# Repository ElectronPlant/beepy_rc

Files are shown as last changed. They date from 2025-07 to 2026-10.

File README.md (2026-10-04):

# BeepyRC
Hobby project to make a RC rover platform using spare RC parts. The goal of this project is to develop a complete platform to support long term RC assisted missions.

Content summary

    * The platform is built on a custom PCB based on a STM32F4 microcontroller.
    * The firmware is implemented using FreeRTOS for simple and reliable multitasking and real-time operation.
    * The enclosure is fully 3d printable.
    * Support for off-the-shelf RC components with SBUS, 5V VTX power output, 3x standard servo outputs.

## Release 1 - [PoC] Nerf Blaster FPV Rover
Minimal-feature rover to support a simple, yet fun mission: exploring the house and firing a Nerf blaster in FPV (First-Person View).

The rover enables you to explore the house remotely using the RC interface and the FPV live feed provided by the video transmitter (VTX). The Nerf blaster and the VTX are mounted on a servo-operated arm, which controls their yaw and pitch angles. The arm provides two extra degrees of freedom to easily explore the room and aim the blaster. Once the target has been acquired, take the shot remotely using the aux channels of the RC remote.

### Complete Rover

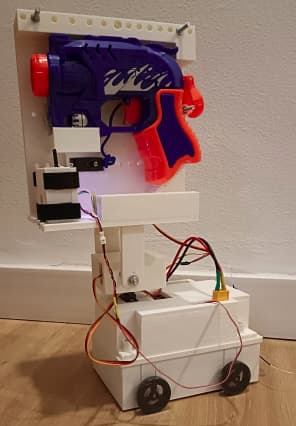
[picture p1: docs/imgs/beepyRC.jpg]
BeepyRc


### Custom PCB

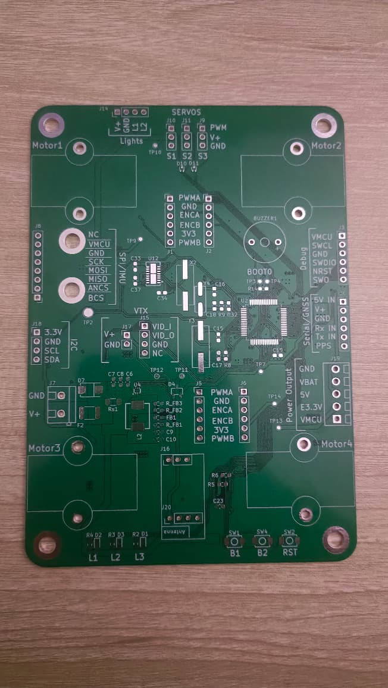
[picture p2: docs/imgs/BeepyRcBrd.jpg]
BeepyRcBrd


### Rover

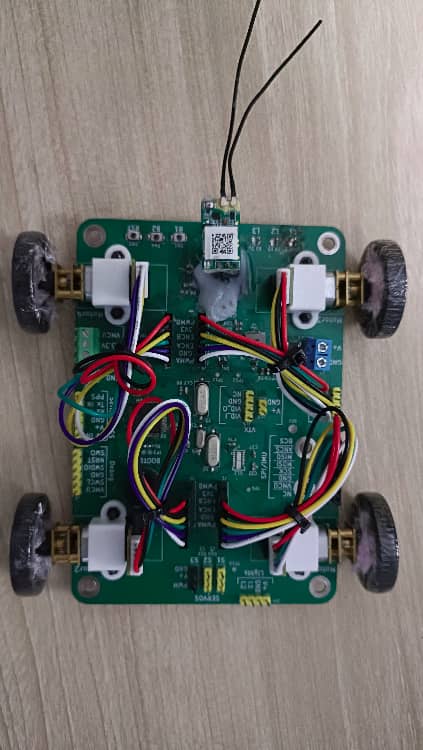
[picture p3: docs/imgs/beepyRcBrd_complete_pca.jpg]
PCA


---

# Documentation
For more information about the project check the documentation in ```docs/``` or deplay with [mkdocs](https://www.mkdocs.org/)

## Installing MKDOCS
run:
```
pip install mkdocs
```
or:
```
python -m pip install mkdocs
```

### Install the Material theme:
```
pip install mkdocs-material
```
or:
```
python -m pip install mkdocs-material
```

### Install mkdoxy
```
pip install mkdoxy
```
or
```
python -m pip install mkdoxy
```

### Install Doxygen
The installation procedure depends on the operating system, see: [Doxygen docs](https://www.doxygen.nl/manual/install.html)

For ubuntu:
```
sudo apt-get install doxygen
```

### Deploy docs
```
mkdocs serve
```

then the documentation will be served at:
```
http://127.0.0.1:8000/
```

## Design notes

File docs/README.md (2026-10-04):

# BeepyRC
Hobby project to make a RC rover platform using spare RC parts. The goal of this project is to develop a complete platform to support long term RC assisted missions.

## Project Roadmap
* [ ] __Release 1: PoC Nerf Blaster FPV Rover__
    * [x] Receive and parse the RC frames.
    * [x] Use RC inputs to control motors.
    * [x] Custom hardware for the RC rover.
    * [X] Control servos with aux channels (camera pan/tilt, fire nerf gun).
    * [X] 3D printed case.
* [ ] __Release 2: Sensor-Assisted Rover__
    * [ ] Motor encoders for precise individual motor adjustments.
    * [ ] Accelerometer, gyroscope and barometer integration speed and rotation RC setpoints.
* [ ] __Release 3: Waypoint Mission Rover__
    * [ ] Odometry + Kinematic movement estimation.
    * [ ] GPS integration for accurate rover position.
    * [ ] Support for autonomous waypoint missions.
* [ ] __Release 4: Autonomous Robotic Platform__

---

# Releases

Release table linking releases with the supported versions and tags.

| Release | FW Version | HW Version | Mech Version |
|---|---|---|---|
| __Rel. 1__  | FWv0.0 | beepyRcBrd_rev0.0 | TODO |

# Versions

Each component has its own versioning which are independent from the releases. This allows reusing a given version on multiple releases, or having multiple versions compatible between releases for patches and improvements.

## Firmware Versions

| Version | Tag | Description|
|---|---|---|
| __V 0.0__ | [FWv0.0](https://github.com/ElectronPlant/beepy_rc/releases/tag/FWv0.0) | Minimal features for Release 1 |

## Hardware

| Version | Tag | Schematics | Reworks | Fabrication Files| Description |
|---|---|---|---|---|---|
| __REV 0.0__ | [beepyRcBrd_rev0.0](https://github.com/ElectronPlant/beepy_rc/tree/beepyRcBrd_rev0.0)| [Schematics](beepyRcBrd/rev_0_0/beepyRcBrd_rev_0_0.pdf) | [Reworks](beepyRcBrd/rev_0_0/reworks.md) |[Fabrication Files](beepyRcBrd/rev_0_0/fabrication_files.zip)| Preliminary support for all planned features. Checkout the [design notes](beepyRcBrd/rev_0_0/design_notes.md). |

## Mechanical

| Version | Tag | STL Files| Description |
|---|---|---|---|
| __REV 0.0__ | [mech_rev0.0](https://github.com/ElectronPlant/beepy_rc/releases/tag/Mech_rev0.0)| [STL](mech/rev_0_0/BeepyRcMech_rev_0_0.zip) | See [Docs](mech/mech_docs.md) |

---

## Getting started

For information on how to get started with the template, refer to the:

* [Hardware](getting_started/hardware.md) page for information on how to setup the module and connect the LEDs used by the application.
* [Setup](getting_started/setup.md) page for a summarized description of how to get the STM32 development environment in a windows PC.

### Repository Organization

The documentation (as required by MkDocs) is placed in the ```docs\``` directory.

The application is implemented in the ```firmware/``` directory, see the [doxygen files output](template/files.md) for further information about the internal organization.

The design files for the custom PCB are located in the ```hardware/``` directory.

The 3D printed case is located in the ```mechanical/``` directory.

## Credits
This projects uses external libraries that are documented in the ```NOTICE.md``` file in the
project's root directory.

More information on used external libraries an reference projects can be seen [credits](about/credits.md)

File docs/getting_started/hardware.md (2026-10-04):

# Hardware

## RC Components

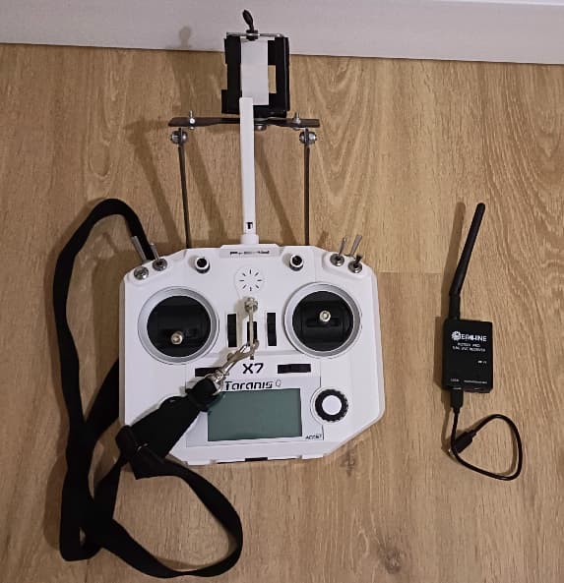
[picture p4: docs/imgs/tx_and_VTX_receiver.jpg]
Radio components


### Radio
I'm using my old [FrSky Taranis Q x7](https://www.frsky-rc.com/product/taranis-q-x7-2/) TX as the remote.

The receiver for the TX is done using the [XM+ FrSky receiver](https://betafpv.com/products/frsky-xm-sbus-mini-receiver) ([manual](https://www.frsky-rc.com/wp-content/uploads/2017/07/Manual/Manual-XM%2B.pdf)). This module uses an SBUS (Check [SBUS](../notes/sbus.md)) interface to connect to the MCU.

### Video Transmitter (VTX)

Again i'm using the VTX from my old tiny whoop. In my case i'm using the [TX06 from Eachine](https://www.eachine.com/Eachine-TX06-700TVL-FOV-130-Degree-5_8Ghz-40CH-Smart-Audio-Mini-FPV-Camera-AIO-Transmitter-For-RC-Dr-p-1418.html). This VTX has support for smart audio and OSD, which are not supported at the moment.

There are multiple compatible receivers. I'm using the [ROTG01 Pro](https://www.eachine.com/Eachine-ROTG01-Pro-UVC-OTG-5_8G-150CH-Full-Channel-FPV-Receiver-W-or-Audio-For-Android-Smartphone-Black-p-1246.html) receiver which connects to my phone to display and store the video feed. On the phone I'm using the FPViewer App.

## Motor Driver

Information about the motor driver and motor used can be seen in the [motor driver](../notes/motor_driver.md) page.

## MCU

### Nucleo
The initial development of the RC-Rover is done on an STM32 nucleo board:

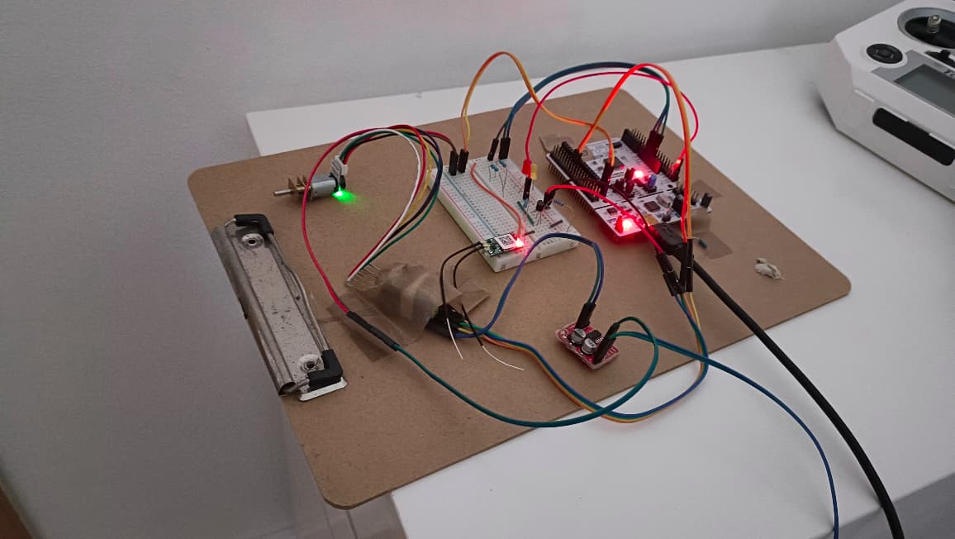
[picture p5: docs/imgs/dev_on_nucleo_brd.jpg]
nucleo development


* Board: Nucleo-F446RE
* MCU: STM32F446RET6

Important links:

* [Datasheet](https://www.st.com/resource/en/data_brief/nucleo-f446re.pdf)
* [Information page](https://www.st.com/en/evaluation-tools/nucleo-f446re.html)
* [Schematic](https://www.arrow.com/en/reference-designs/nucleo-f446re-stm32-nucleo-development-board-with-stm32f446ret6-mcu-supports-arduino-and-st-morpho-connectivity/f2ac4e6d8d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)

The different components (e.g. motor driver, SBUS, etc.) need to be connected following the definitions in
```firmware/target/nucleo/target.c```

#### Pin Out
![image](../imgs/nucleo_pinout.jpg)

[image source](https://www.thegioiic.com/upload/large/48757.jpg)

### BeepyRcBoard

![nucleo development](../imgs/dev_on_beepy_rc.jpg)

* Check [main](../README.md) for information on the latest board releases, and board files.
* Check [design notes](../beepyRcBrd/rev_0_0/design_notes.md) for information on the board design decisions.

The board can be flashed and the debug traces received using the Nucleo board, after adjusting the jumper bridges on CN2, (see [tutorial](https://www.radioshuttle.de/en/turtle-en/nucleo-st-link-interface-en/)).

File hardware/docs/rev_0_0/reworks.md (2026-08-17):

# Reworks for Rev 0.0

## 5V Enable Circuit Capacitor
The capacitor for the 5V enable circuit (C12) needs to be replaced by a _100uF_ capacitor. The 5V rail is enabled using an SR latch. The latch allows the MCU to disable the 5V rail keeping off until the battery is physically disconnected and reconnected after a few seconds. When the battery is first connected, the C12 capacitor keeps the NS input of the latch low long enough to set the latch. The timing needs to be increased for the circuit to work properly.

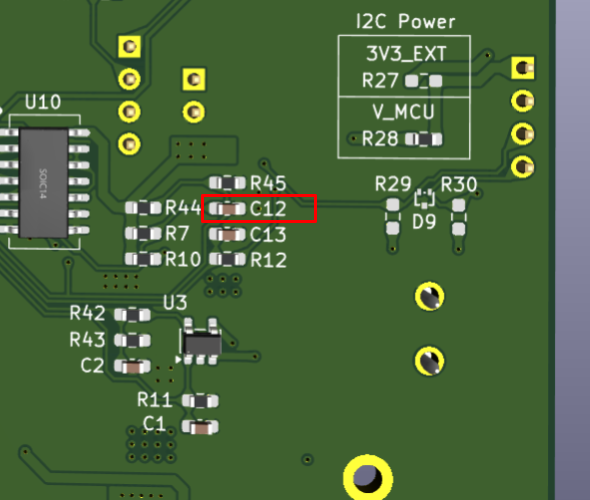
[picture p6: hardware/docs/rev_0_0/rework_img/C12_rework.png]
C12 cap rework


## Green LED
The green LEDs where not turning on due to their higher forward voltage rating compared to the other colors. This is fixed by replacing the green LED (D2) with a yellow LED (PN: C125100).

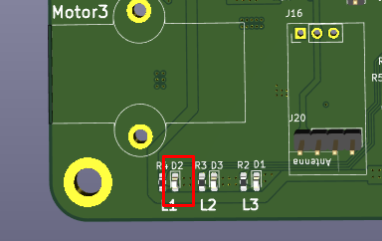
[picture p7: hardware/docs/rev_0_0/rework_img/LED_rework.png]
Green LED rework


## RC Pins Reversed
The Pins for the RC module are reversed for J16. There are three options to fix this. I used the last one despite it requiring more work, it keeps the RC module more or less in the original orientation.

1. Place the module rotated with the antenna towards the center of the board.
2. Place the module with the bind button facing down.
3. Glue a different connector and use wires to swap the pins.

## Motor Drivers
There are two different fixes required for the motor drivers (TC118S). First, the maximum motor voltage rating for the ICs is 9V, which is lower than the accepted battery voltage. Lastly, the supply voltage needs a decoupling capacitor to operate as expected.

This rework is more complex than the rest, and require the following steps:

1. Before soldering the IC to the board, fold pin 4 (VDD) so that it does not touch the pad.
2. Solder the IC except for pin 4.
3. Short pin 7 (PGND) and pin 6 (AGND).
4. Solder a 4.7uF capacitor between the shorted pins 7 and 6 and pin 4.
5. Add a wire between pin 4 and V_Servo.

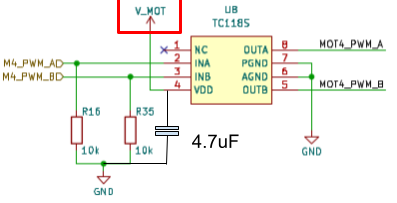
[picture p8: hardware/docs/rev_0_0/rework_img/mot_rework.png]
TC118S


## Lights Enable
The lights enable signal is not connected to the MCU. For now no rework has been proposed for this, since there are no GPIOs available.

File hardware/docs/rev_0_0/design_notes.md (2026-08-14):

# General Notes on the PCB Design

## Intro

The schematics and the PCB design are being done with Kicad.

The basic information about the requirements for the MCU are based on the following documents:

* [MCU datasheet](https://www.st.com/resource/en/datasheet/stm32f446re.pdf)
* [STM32 hardware guidelines](https://www.st.com/resource/en/application_note/an4488-getting-started-with-stm32f4xxxx-mcu-hardware-development-stmicroelectronics.pdf)
* [Clock appliction note](https://www.st.com/resource/en/application_note/cd00221665-oscillator-design-guide-for-stm8af-al-s-stm32-mcus-and-mpus-stmicroelectronics.pdf)

## References

Reference designs:

* [Simon Says](https://github.com/ElectronPlant/Simon_says_ATtiny/blob/master/Hardware/Simon_says_Attiny_Print_Schematics.pdf)
* [Flight controller](https://easyeda.com/editor#id=fbe44b42766e4ebb9b2bbff61543d910)
* [Flight controller 2](https://github.com/nppc/FF4Nano/blob/master/FF4NanoUSB.pdf)
* [Guide for fight controllers](https://flying-rabbit-fpv.com/2020/10/06/designing-my-own-flight-controller/)
* [STM32 example](https://stm32world.com/images/1/16/MCUSTM32F446_rev._a_schematics.svg)
* [Nucleo board schematic](https://www.st.com/resource/en/schematic_pack/mb1136-default-c03_schematic.pdf)

# Design notes

## MCU

### Debugging

The debugging will be done with the STLink V2 debugger. There is the STLink V3 version, but
this is not selected since it is not the one used by the Nucleo board (it may not be supported) by
the MCU.

A guide on debugging for STM32 can be seen [here](https://stm32-base.org/guides/connecting-your-debugger.html).
There are different pinouts that may be used. The PCB will be done using the Nucleo output.

There is also the debugging UART interface. This interface may be used for configurations or user level information.
This UART interface can be implemented using USB phy of the STM, using an external UART to USB adapter IC, or relying on an external UART to USB module. To minimize the development efforts and the component count on the PCB, the debugging UART interface will rely on the external UART to USB module (e.g. [see link](https://www.robotics-university.com/2018/04/usb-to-uart-ttl-bridge-cp2102-module.html)).

### Power, Grounding and Debugging

The MCU will be powered from a 3.3V rail.
The decoupling strategy is done following page 9 from [AN4488](https://www.st.com/resource/en/application_note/an4488-getting-started-with-stm32f4xxxx-mcu-hardware-development-stmicroelectronics.pdf).

* There is one 10uF capacitor for the MCU
* There is one additional 100nF cap for each VDD and VSS pair.
* Since there is no battery onboard, Vbat is connected to VDD with an additional 100nF cap.
* VDDA is connected to VDD through a ferrite bead.
* VDDA and VSSA are decoupled using a 1uF and a 100nF cap.
* GNDA is directly connected to GND.

### Clocks

There are two crystals used for the MCU. This approach is based on what exists on the Nucleo board.
The design and value calculation of the capacitor and external resistors is based on [AN2867](https://www.st.com/resource/en/application_note/cd00221665-oscillator-design-guide-for-stm8af-al-s-stm32-mcus-and-mpus-stmicroelectronics.pdf).

#### HSE

HSE, the high frequency clock is set at 8MHz, following the suggestions on keeping it as low as possible (reference pending).

Part: [HY8M49SSMDOB2R20](https://jlcpcb.com/partdetail/Huiyuancrystal-HY8M49SSMDOB2R20/C5265773)

#### LSE

LSE, the low frequency clock is set to 32.768kHz.

Part: [M332768DWNAC](https://www.lcsc.com/product-detail/C2838416.html)

## Power

There are two options to power the board, the external battery or the Debug USB.

The external battery (2s lipo battery from 6 to 12V). This source is current limited to 6A and has reverse voltage protection with the TVS and the current limiting PTC.
__Note__: there is no over-discharge protection built into the battery. This is intentional, since high current spikes will cause the battery voltage to sag and falsely trigger any protection. Instead, the MCU is responsible for monitoring battery voltage and disabling the regulated 5 V rail if necessary. This 5 V rail powers all components except the motors, which only run when explicitly controlled by the MCU. Once the 5 V rail is disabled, the board remains idle until the battery is disconnected for a few seconds and then reconnected.

5V input on the Debug USB. This source only supplies the core functionality (i.e. everything except for the motors, servos, VTX, external 3V3 rail).
The input is current limited to 500mA and reverse voltage protected with the OR diodes.

In case both sources are connected at the same time the OR diodes will select the higher voltage source.

### Distribution
The battery input is current-limited to 6A, supplying both the drive motors and the 5 V buck converter.
Of this 6 A:

* 2A are allocated for the drive motors.
* 4A are available for the 5V buck converter.

The 5 V buck converter powers:

* Servos and night lights: up to 2.6A.
* Video transmitter (VTX): up to 500mA.
* External 3.3 V source: up to 500mA, intended as a backup to power additional external sensors (e.g. GPS).
* Core functionality: 400mA, which may also be supplied from the debug USB 5V rail.

The core functionality 5V source powers:

* the RC module (up to 100mA).
* The remaining 300mA powers the 3.3 V regulator, which supplies the MCU and internal sensors.

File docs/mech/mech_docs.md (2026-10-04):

# Mechanical Release 1.0

## 3D Printable pieces

All 3D printable pieces have been made using Tinkercad, and are available to be remixed directly on their website. The following table links the different parts. The STLs of the parts is available on the repository for ease of use.

| Part | Description|
|---|---|
|[Bottom Enclosure](https://www.tinkercad.com/things/jpuFKT2e5q8-beepyrc-bottom-enclosure) | Bottom enclosure to hold the BeepyRcBrd |
|[Top Enclosure](https://www.tinkercad.com/things/cq1XpsLmDJL-beepyrc-top-enclosure) | Top enclosure that attaches to the bottom enclosure.|
|[Top Enclosure 2](https://www.tinkercad.com/things/cYBVxJHJOmw-beepyrc-top-enclosure-2) | Top part of the top enclosure goes on top of the Top Enclosure part. It houses the battery and pan servo. It uses the Tinkercad community SG90 servo model by Federico Dall'Orso (I was not able to locate the source to link, it can be referenced in the model itself).|
|[Enclosure Bolt Extender](https://www.tinkercad.com/things/6YzsgGTErdm-beepyrc-enclosure-bolt-extender) | M4 bolt extender to connect the top and bottom enclosures using a 30mm M4 bolt from the bottom and a 30mm M4 bolt from the top. It houses 3 M4 bolts. This part may be skip if you find 60mm M4 bolts.|
|[Top Enclosure bolt Extender](https://www.tinkercad.com/things/8HW3N3RYSTf-beepyrc-top-bolt-extender) | Spacer for the top enclosure bolt. It provides spacing between the Top Enclosure 2 and the top enclosure bolt, so it can be tightened correctly. |
|[BeepyRc Tilt Servo Holder](https://www.tinkercad.com/things/kKJ7Aj4eDxs-beepyrc-tilt-servo-holder) | Houses the MG996R servo that controls the tilt angle of the pan-tilt mechanism. It is glued directly to the horn of the pan angle servo. It uses the following [servo horn model](https://www.printables.com/model/1734482-servo-arms/files); and the Tinkercad community MG996R model by Randy Sarafan (I was not able to locate the source to link, it can be referenced in the model itself)|
|[Left Head Bracket](https://www.tinkercad.com/things/hJWzkLlVXu9-beepyrc-left-head-bracket) | Left bracket connecting the tilt servo to the head |
|[Right Head Bracket](https://www.tinkercad.com/things/isPPQw0B1cy-beepyrc-right-head-bracket) | Right bracket support that attached to tilt servo holder to serve as a second anchor point.|
|[BeepyRc Pan-Tilt Head Support](https://www.tinkercad.com/things/aVCM6FixHyH-beepyrc-pan-tilt-head-support) | Support of the pan-tilt mechanism that holds the VTX holder and the Nerf blaster holder.|
|[BeepyRc Back VTX Enclosure](https://www.tinkercad.com/things/5YyXrJhm8Ro-beepyrc-back-vtx-enclosure) | Back side of the the VTX Enclosure. It attaches tot he Pan-Tilt Head Support.|
|[BeepyRc VTX Front Enclosure](https://www.tinkercad.com/things/73pObGXGMkc-beepyrc-vtx-front-enclosure) | Front side of the the VTX Enclosure. It attaches tot he Pan-Tilt Head Support.|
|[BeepyRc Nerf Blaster Holder](https://www.tinkercad.com/things/jVXIg7vj2Tw-beepyrc-nerf-blaster-holder) | Nerf blaster holder, which attaches the nerf blaster and the shooting servo to the Pan-Tilt Head Support. It uses the Tinkercad community SG90 servo model by Federico Dall'Orso (I was not able to locate the source to link, it can be referenced in the model itself). |

## Non 3D printable Parts
| Part | Number | Description|
|---|---|---|
|30mm M4 Bolts | x8 | They can be replaced by x4 60mm bolts. They are used to connect the bottom and top enclosures.|
|50mm M4 Bolts | x4 | - |
| M4 Nuts | x16 | - |
|N20 motors with magnetic encoder | x4 | 6V 1500RPM motors ([example listing](https://es.aliexpress.com/item/1005004999529855.html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)). |
|N20 motor clip | x4 | With bolt and nut ([example listing](https://es.aliexpress.com/item/32814175769.html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)). |
|N20 motor wheels | x4 | [example listing](https://es.aliexpress.com/item/32809043739.html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)|
|SG90 servo| x2| One for the pan angle, and the other to shoot the Nerf blaster.|
|MG996R servo| x1 | For the Tilt angle. |
|BeepyRcBrd | x1 | Mounted. |
|Frsky XM + D16 SBUS | x1 | RC receiver ([example listing](https://es.aliexpress.com/item/32971177875.html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))|
|Battery holder | x1 | Any 6 to 12V battery pack will do the job. I'm using an old 12V AA battery holder |
| Nerf Blaster | x1 | I'm using the [following](https://www.aliexpress.com/item/1005010455817038.html?spm=a2g0o.order_list.order_list_main.15.3d49194dc47Stv) |

---

## Mounting summary

### Step 0 - Complete the PCA
Start by attaching, and wiring the ``N20 motors`` to the BeepyRcBrd PCA. Follow the wiring indication on the BeepyRcBrd silkscreen. The N20 motors come with the bare wires, so there is the option to solder the wires to the board, or crimp Dupont wires to perform the connections (this is the option I followed, but requires having the crimping tool). Complete the motor installation by connecting the wheels to the N20 motor shafts.

To improve steering, I covered the wheels in plastic wrap. This is needed due to the drift-based steering of 4wd vehicles. This is something to be improved in future releases.

continue by attaching the ``Frsky XM + D16 SBUS`` RC receiver (note that there is a rework to fix the wiring).

Finally, make sure the MCU is programmed, since it would not be possible to do so beyond this point without disassembling the rover.

At this point the BeepyRcBrd PCA should look as follows

BeepyRcBrd PCA complete

### Step 1 - Bottom Enclosure

The BeepyRCBrd PCA is attached to the ``Bottom Enclosure`` using x4 30mm M4 bolts, and the cylindrical part of the ``Enclosure Bolt Extender``. Note that on the bottom part of the bolt extender there is a hole for an M4 bolt, that will hold the BeepyRcBrd.

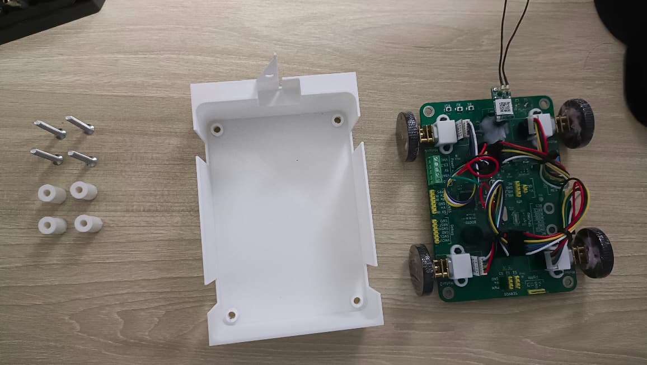
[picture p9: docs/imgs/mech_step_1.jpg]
Step 1


### Step 2 - Top Enclosures

Before placing the ``Top Enclosure`` make sure to connect the servo, and battery wires to tbe BeepyRcBrd, passing the wire through the ``Top Enclosure`` cable hole.

Follow by placing the second piece of the ``Enclosure Bolt Extender`` needs to be screwed to the ``Bottom Enclosure`` bolts from the step before. This piece has holes for two M4 nuts, which need to be filled first. The bottom nut will be screwed to the ``Bottom Enclosure``'s bolts, while the top nut will be screwed later from the top.

Then, place the ``Top Enclosure`` on the ``Bottom Enclosure``. Note that there is a tab for the antenna holder that needs to be aligned.

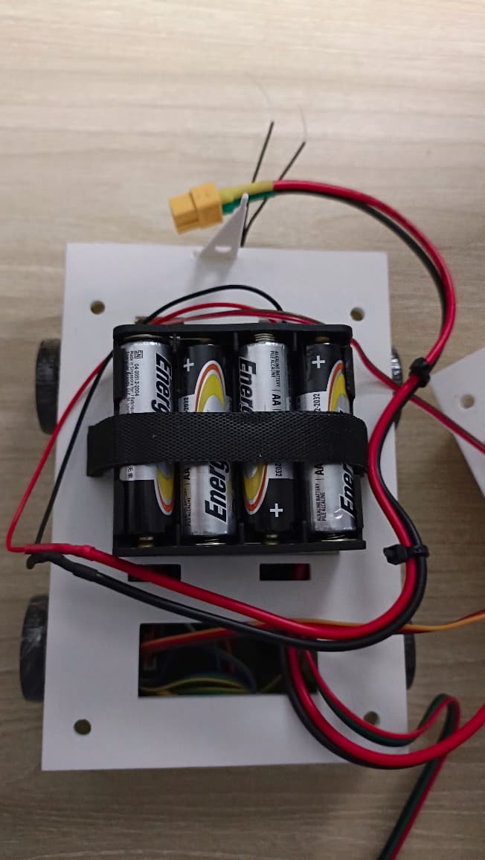
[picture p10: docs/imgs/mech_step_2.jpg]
Step 2


### Step 3 - Pan Servo

Attach the pan ``SG90 servo`` to the servo mount on the ``Top Enclosure 2`` part. There are two screw holds that can be used to secure the servo.

Instead of a power on switch, I'm using a XT60 connector to connect/disconnect the power. There is a hole for this on the ``Top Enclosure 2``.

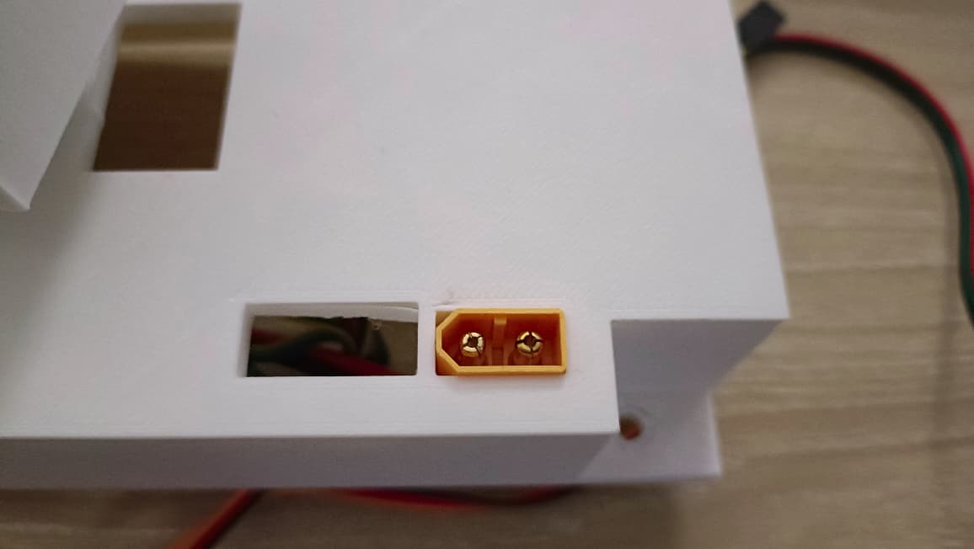
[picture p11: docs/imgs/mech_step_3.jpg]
Step 3


### Step 4 - Tilt Servo

First pass a 50mm M4 screw to that it is sticking out from the ``Tilt Servo Holder`` and use a M4 bolt to hold it in place.

Then, attach the tilt ``MG996R servo`` to the ``Tilt Servo Holder``. There are four screw holes for the servo screws to keep it in place. Do not attach any of the horns for now.

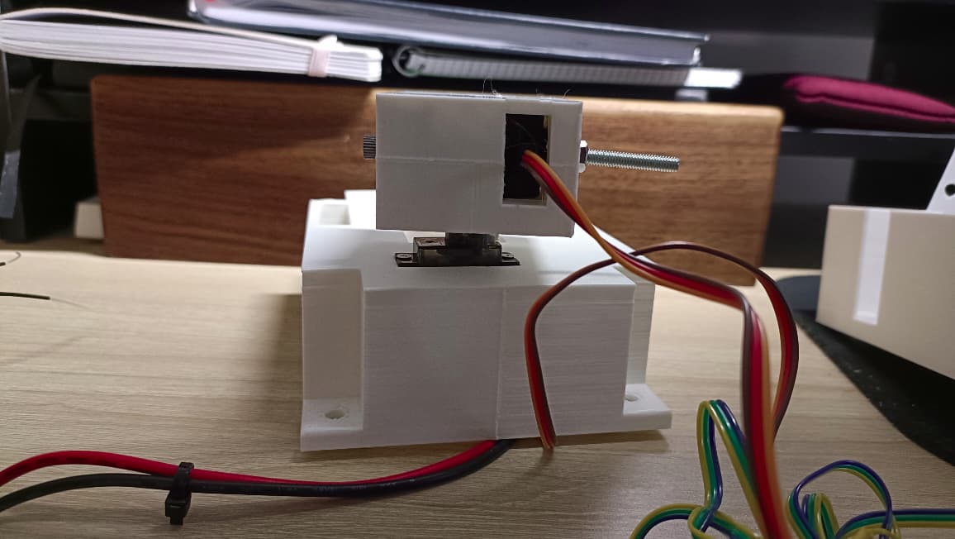
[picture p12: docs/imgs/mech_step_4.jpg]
Step 4


### Step 5 - Pan-Tilt Head Assembly

Attach the VTX on its enclosure using cable ties. Then, attach the assembly to the ``Pan-Tilt Head Support`` also using cable ties.

The Nerf blaster holder has a mounting hole for the shooting ``SG90 servo``, which can also be screwed to be kept in place.
The ```Nerf Blaster Holder`` is intended to keep the Nerf blaster in place without having to glue it in. The top and bottom holes on the holder are available to tie the blaster with strings if needed. It ended not being needed on my case.

Then, the shooting servo needs to be able to shoot the blaster. I modified to Nerf blaster's trigger to pass a wire that is connected ot the servo. Thus, when the servo rotates the trigger is actuated.

Finally, attach the ``Nerf Blaster Holder`` assembly to the ``Pan-Tilt Head Support``. There is a M4 screw hole to keep it in place. But it needs to be glued in place to prevent it from rotating.

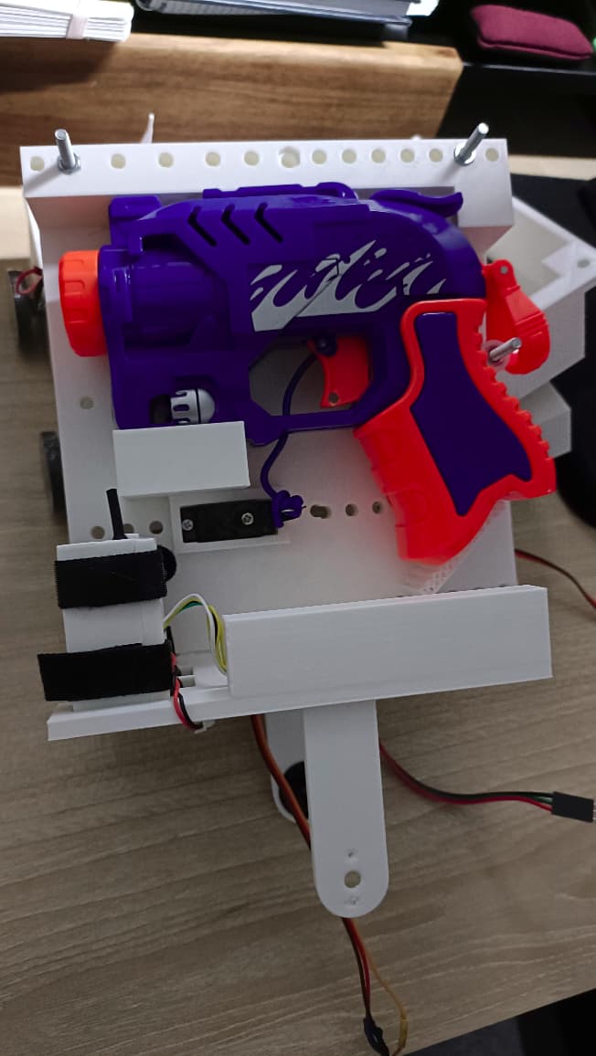
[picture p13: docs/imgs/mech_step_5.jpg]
Step 5


### Step 6 - Head brackets

The ``Head Brackets`` are directly glued to the ``Pan-Tilt Head Support``. There are two tabs on the bottom part of the ``Pan-Tilt Head Support`` for each bracket. Check the image for the required orientation.

The ``Left Head Bracket`` has a hole for the circular horn that comes with the ``MG996R servo``. The horn needs to be glued to the bracket.

Step 5

### Step 6 - Final Step

Finally, attach the ``Pan-Tilt Head Assembly`` to the main body. First pass the M4 bolt on the ``Tilt Servo Holder`` assembly through the M4 hole on the ``Right Head Bracket``. Use a nut to keep it in place. Then, Screw the circular horn glued to the ``Left Head Bracket`` to the tilt servo.

Step 6

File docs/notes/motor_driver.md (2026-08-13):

# Motor Driver

## Notes on the motor brushed motor driver.

There are two types control according to [DRV883x datasheet](https://lcsc.com/datasheet/lcsc_datasheet_2410122006_Texas-Instruments-DRV8837DSGR_C39159.pdf)

* __PWM (IN/IN):__ This is the case of the motor driver used in this project. The speed is controlled by setting one of the inputs to a fixed value, and having the PWM on the other. Then, to go on reverse, the PWM and fixed output are swapped.
* __Phase-Enable (PH/EN):__ This is the most straight forward case, the speed is controlled through the enable input and the direction is controlled by the phase input.

The problem with the PWM control approach is that the PWM needs to be applied through a different pin depending on the motor direction.
Normally, this is not ideal since each timer output is assigned to a given pin. This requires having two channels per motor or adding extra logic.
An example of this can be seen in the [following repository](https://github.com/NicholasBerryman/GenericMotorDriver/tree/master), where the motor is controlled using two PWM output pins.

The problem with the phase-enable motor drivers is that they are significantly less available. Thus, depending on them will make the design harder or more costly.

There are other type of interfaces which are a combination using two pins for the direction control and one enable pin to handle the PWM
(e.g. [L298N](https://www.st.com/resource/en/datasheet/l298.pdf))

## PWM (IN/IN) Motor Drivers

These drivers operate according to the following table (or a similar version of it).

| IN1 | IN2 | OUT1 | OUT2 | Mode |
|-----|-----|---|---|--- |
| 0 | 0 | Z | Z | Coast |
| 1 | 0 | H | L | Forward |
| 0 | 1 | L | H | Reverse |
| 1 | 1 | L | L | Break |

There are two options to apply the PWM:

1. The _off_ state is coast, so both terminal of the H-bridge are off.
2. The _off_ state is break, so both terminals of the H-bridge are shorted through GND.

With option 1, during the _off_ state, the energy of the motor discharges slowly through the MOSFET's body diodes. If the frequency is too low the motor may not start (MX1616 driver)
With option 2, the motor breaks during the _off_ state. This enables accurate speed control. However, if the frequency is too low, the breaking may make the spinning be not smooth.

After some initial testing it was decided to go with _option 2_ as it provided a more accurate speed control. The PWM frequency will be kept high enough to avoid the negative effects.

# Test Motor Diver

The initial implementation will be done using a [MX1616](https://datasheet.lcsc.com/lcsc/2207251030_Mixic-MX1616H_C5119044.pdf) module I had around. Then, the board will evaluate different motor divers.

* [Tutorial](https://www.instructables.com/Tutorial-for-Dual-Channel-DC-Motor-Driver-Board-PW/)

# Motor information

The motors used for the project are N20 motors from aliexpress.

Characteristics:

* Voltage: 6V
* RPM: 1500RPM
* Logic voltage: 5V - 3.3V
* [Datasheet](https://cdn-shop.adafruit.com/product-files/4640/n20+motors_C15011+6V.pdf)
* [Usefull info](https://docs.cirkitdesigner.com/component/72ca542f-9daa-409a-9db7-2735e4f8f9b2/n20-motor-with-encoder)

The internal circuitry of the encoders directly generates the encoder signals as a digital wave.

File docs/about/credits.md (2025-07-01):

# Credits

## Sources

* The starting point for this project is code generate with SMT32CubeMx and the SMT32 LL (Low Level) libraries.
    * [STM32CubeMX](https://www.st.com/en/development-tools/stm32cubemx.html).
    * [STM32f4xx HAL](https://github.com/STMicroelectronics/STM32CubeF4)
    * [STM32CubeF4 repository](https://github.com/STMicroelectronics/STM32CubeF4)
* The formatting using for this project is taken from the .clang-format file proposed by YodaEmbedding
    * [repository](https://gist.github.com/YodaEmbedding/c2c77dc693d11f3734d78489f9a6eea4)
* The documentation is generated using [MkDocs](https://www.mkdocs.org/) with the [Material theme](https://github.com/squidfunk/mkdocs-material) with [mkdoxy](https://github.com/JakubAndrysek/mkdoxy) to add the [Doxygen](https://www.doxygen.nl/) generated documentation.

## Inspiration
list of similar projects. This list is not intended to be comprehensive, and will be extended as more examples are located.

### Main inspiration
* [Betaflight](https://github.com/betaflight)
* [ArduPilot](https://github.com/ArduPilot/ardupilot)

### SBUS
* [Betaflight](https://github.com/betaflight)
* [Bolder Flight Systems](https://github.com/bolderflight/sbus/tree/main)

## Assets
None

### LOGO
* Test logo is made with [Draw.io](https://www.drawio.com/).

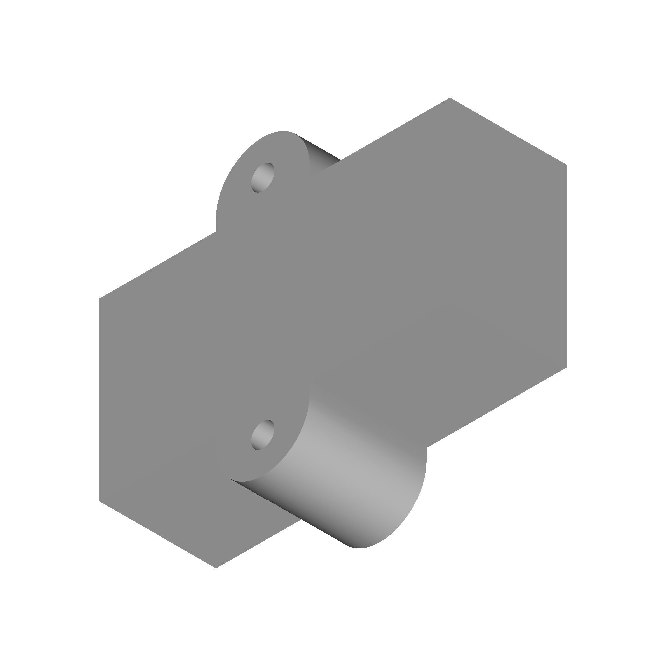
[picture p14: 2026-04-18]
hardware/docs/models/Motor.jpg

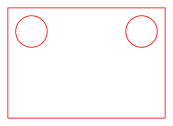
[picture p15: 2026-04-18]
hardware/docs/models/GY-91.png

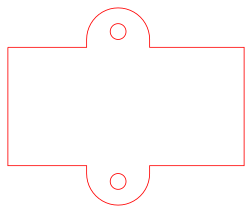
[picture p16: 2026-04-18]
hardware/docs/models/Motor.png

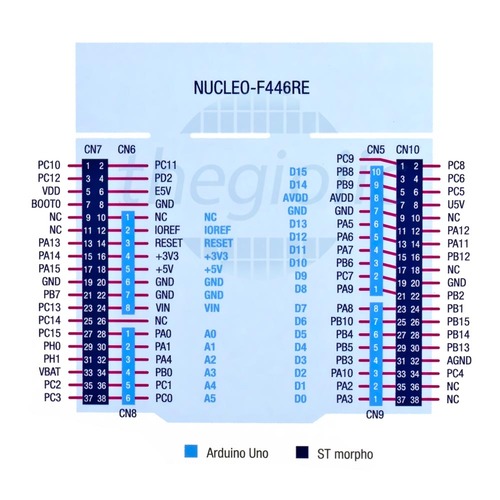
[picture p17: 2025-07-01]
docs/imgs/nucleo_pinout.jpg

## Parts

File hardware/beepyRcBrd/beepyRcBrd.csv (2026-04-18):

Reference | Qty | Value | DNP | Exclude from BOM | Exclude from Board | Footprint | Datasheet
BUZZER1 | 1 | TMB12A05 |  |  |  | beepyRcBrd:BUZ-TH_BD12.0-P7.60-D0.6-FD | https://lcsc.com/product-detail/Buzzers_TMB12A05_C96093.html
C1 | 1 | 5.1nF |  |  |  | beepyRcBrd:C_0603_1608Metric_Pad1.08x0.95mm_HandSolder | ~
C2 | 1 | 18nF |  |  |  | beepyRcBrd:C_0603_1608Metric_Pad1.08x0.95mm_HandSolder | ~
C3,C4,C5,C11,C27 | 5 | 1μF |  |  |  | beepyRcBrd:C_0603_1608Metric_Pad1.08x0.95mm_HandSolder | ~
C6,C7,C20 | 3 | 10μF |  |  |  | beepyRcBrd:C_0603_1608Metric_Pad1.08x0.95mm_HandSolder | ~
C8,C21,C22,C23,C24,C25,C26,C28,C30,C33,C34,C37 | 12 | 100nF |  |  |  | beepyRcBrd:C_0603_1608Metric_Pad1.08x0.95mm_HandSolder | ~
C9,C10,C14,C29 | 4 | 22μF |  |  |  | beepyRcBrd:C_0603_1608Metric_Pad1.08x0.95mm_HandSolder | ~
C12,C13 | 2 | 10nF |  |  |  | beepyRcBrd:C_0603_1608Metric_Pad1.08x0.95mm_HandSolder | ~
C15,C17 | 2 | 30pF |  |  |  | beepyRcBrd:C_0603_1608Metric_Pad1.08x0.95mm_HandSolder | ~
C16,C18 | 2 | 14pF |  |  |  | beepyRcBrd:C_0603_1608Metric_Pad1.08x0.95mm_HandSolder | ~
C19 | 1 | 4.7μF |  |  |  | beepyRcBrd:C_0603_1608Metric_Pad1.08x0.95mm_HandSolder | ~
D1 | 1 | RED |  |  |  | beepyRcBrd:LED_0603_1608Metric_Pad1.05x0.95mm_HandSolder | ~
D2 | 1 | GREEN |  |  |  | beepyRcBrd:LED_0603_1608Metric_Pad1.05x0.95mm_HandSolder | ~
D3 | 1 | YELLOW |  |  |  | beepyRcBrd:LED_0603_1608Metric_Pad1.05x0.95mm_HandSolder | ~
D4 | 1 | SDM20E40C-7-F |  |  |  | beepyRcBrd:SOT-23-3_L2.9-W1.6-P1.90-LS2.8-BR | https://lcsc.com/product-detail/Schottky-Barrier-Diodes-SBD_DIODES_SDM20E40C-7-F_SDM20E40C-7-F_C139437.html
D5 | 1 | D_Schottky |  |  |  | beepyRcBrd:D_SOD-323 | ~
D6,D8 | 2 | CDSOT23-SM712 |  |  |  | beepyRcBrd:SOT-23_L2.9-W1.3-P1.90-LS2.4-BR | https://lcsc.com/product-detail/Diodes-ESD_BOURNS-CDSOT23-SM712_C404012.html
D7 | 1 | SMBJ15A_C83846 |  |  |  | beepyRcBrd:SMB_L4.6-W3.6-LS5.3-RD | https://lcsc.com/product-detail/Others_Littelfuse_SMBJ15A_Littelfuse-SMBJ15A_C83846.html
D9 | 1 | UESD3.3DT5G |  |  |  | beepyRcBrd:SOT-723_L1.2-W0.8-P0.40-LS1.2-BR | https://lcsc.com/product-detail/Others_ON-Semicon_UESD3-3DT5G_ON-Semicon-ON-UESD3-3DT5G_C233435.html
D10,D11,D12,D13,D14,D15 | 6 | UESD3.3DT5G | DNP |  |  | beepyRcBrd:SOT-723_L1.2-W0.8-P0.40-LS1.2-BR | https://lcsc.com/product-detail/Others_ON-Semicon_UESD3-3DT5G_ON-Semicon-ON-UESD3-3DT5G_C233435.html
F1 | 1 | MINISMDC050F-2 |  |  |  | beepyRcBrd:Fuse_1812_4532Metric_Pad1.30x3.40mm_HandSolder | ~
F2 | 1 | BSMD1812L-600-12V |  |  |  | beepyRcBrd:Fuse_1812_4532Metric_Pad1.30x3.40mm_HandSolder | ~
FB1,FB2 | 2 | FerriteBead |  |  |  | beepyRcBrd:R_0603_1608Metric_Pad0.98x0.95mm_HandSolder | ~
H1,H2,H3,H4,H13,H14 | 6 | MT |  | Excluded from BOM |  | beepyRcBrd:MountingHole_4.3mm_M4_DIN965_Pad_TopBottom | ~
H5,H6,H7,H8,H9,H10,H11,H12 | 8 | MT |  | Excluded from BOM |  | beepyRcBrd:MountingHole_2.2mm_M2_DIN965_Pad_TopBottom | ~
J1,J2,J3,J4,J5,J6 | 6 | Conn_01x06 |  |  |  | beepyRcBrd:PinHeader_1x06_P2.54mm_Vertical | ~
J7 | 1 | Conn_01x02 |  |  |  | beepyRcBrd:CONN-TH_P5.00_KF301-5.0-2P | ~
J8 | 1 | Conn_01x08 |  |  |  | beepyRcBrd:gy91 | ~
J9,J10,J11 | 3 | Conn_01x03 |  |  |  | beepyRcBrd:PinHeader_1x03_P2.54mm_Vertical | ~
J14,J15,J18,J20 | 4 | Conn_01x04 |  |  |  | beepyRcBrd:PinHeader_1x04_P2.54mm_Vertical | ~
J16 | 1 | Conn_01x03 |  |  |  | beepyRcBrd:rc | ~
J17 | 1 | Conn_01x02 |  |  |  | beepyRcBrd:PinHeader_1x02_P2.54mm_Vertical | ~
J19 | 1 | Conn_01x05 |  |  |  | beepyRcBrd:CONN-TH_5P-P3.50_DORABO_DB125-3.5-5P-GN-S | ~
L2 | 1 | 1.8μH |  |  |  | beepyRcBrd:IND-SMD_L7.0-W6.6_MCW-0650-220 | ~
Q1,Q2,Q4,Q5 | 4 | BSS138LT1G |  |  |  | beepyRcBrd:SOT-23-3_L2.9-W1.6-P1.90-LS2.8-BR | https://lcsc.com/product-detail/MOSFET_ON_BSS138LT1G_BSS138LT1G_C82045.html
Q3 | 1 | BSS138DW-7-F |  |  |  | beepyRcBrd:SC-70-6_L2.2-W1.3-P0.65-LS2.1-TL | https://lcsc.com/product-detail/MOSFET_DIODES_BSS138DW-7-F_BSS138DW-7-F_C154900.html
R1,R5,R6,R14,R16,R19,R20,R35,R36,R37,R38,R39,R40,R41,R43,R45 | 16 | 10k |  |  |  | beepyRcBrd:R_0603_1608Metric_Pad0.98x0.95mm_HandSolder | ~
R2,R3,R4 | 3 | 2.2k |  |  |  | beepyRcBrd:R_0603_1608Metric_Pad0.98x0.95mm_HandSolder | ~
R7,R10,R12 | 3 | 51k |  |  |  | beepyRcBrd:R_0603_1608Metric_Pad0.98x0.95mm_HandSolder | ~
R8 | 1 | 604R |  |  |  | beepyRcBrd:R_0603_1608Metric_Pad0.98x0.95mm_HandSolder | ~
R9 | 1 | 150k |  |  |  | beepyRcBrd:R_0603_1608Metric_Pad0.98x0.95mm_HandSolder | ~
R11 | 1 | 30k |  |  |  | beepyRcBrd:R_0603_1608Metric_Pad0.98x0.95mm_HandSolder | ~
R13,R21,R28 | 3 | 0 |  |  |  | beepyRcBrd:R_0603_1608Metric_Pad0.98x0.95mm_HandSolder | ~
R15,R27 | 2 | 0 | DNP |  |  | beepyRcBrd:R_0603_1608Metric_Pad0.98x0.95mm_HandSolder | ~
R17,R18 | 2 | 51R |  |  |  | beepyRcBrd:R_0603_1608Metric_Pad0.98x0.95mm_HandSolder | ~
R23,R24,R25,R26 | 4 | 22R |  |  |  | beepyRcBrd:R_0603_1608Metric_Pad0.98x0.95mm_HandSolder | ~
R29,R30 | 2 | 10k | DNP |  |  | beepyRcBrd:R_0603_1608Metric_Pad0.98x0.95mm_HandSolder | ~
R31 | 1 | 100R |  |  |  | beepyRcBrd:R_0603_1608Metric_Pad0.98x0.95mm_HandSolder | ~
R32 | 1 | 200k |  |  |  | beepyRcBrd:R_0603_1608Metric_Pad0.98x0.95mm_HandSolder | ~
R33,R34 | 2 | 75R |  |  |  | beepyRcBrd:R_0603_1608Metric_Pad0.98x0.95mm_HandSolder | ~
R42 | 1 | 40k |  |  |  | beepyRcBrd:R_0603_1608Metric_Pad0.98x0.95mm_HandSolder | ~
R44 | 1 | 50k |  |  |  | beepyRcBrd:R_0603_1608Metric_Pad0.98x0.95mm_HandSolder | ~
Rs1 | 1 | 17m |  |  |  | beepyRcBrd:R_1206_3216Metric_Pad1.30x1.75mm_HandSolder | ~
R_FB1 | 1 | 49k |  |  |  | beepyRcBrd:R_0603_1608Metric_Pad0.98x0.95mm_HandSolder | ~
R_FB2,R_FB3 | 2 | 3k |  |  |  | beepyRcBrd:R_0603_1608Metric_Pad0.98x0.95mm_HandSolder | ~
SW1,SW2,SW4 | 3 | SW_Push |  |  |  | beepyRcBrd:SW-SMD_L3.9-W3.0-P4.45 | ~
TP2 | 1 | TestPoint |  |  |  | beepyRcBrd:TestPoint_Pad_D2.5mm | ~
TP3,TP4,TP7,TP9,TP10,TP11,TP12,TP13,TP14 | 9 | TestPoint |  |  |  | beepyRcBrd:TestPoint_Pad_D1.0mm | ~
U1,U6,U7,U8 | 4 | TC118S |  |  |  | beepyRcBrd:SOP-8_L4.9-W3.9-P1.27-LS6.0-BL | https://lcsc.com/product-detail/Motor-Drivers_TC118S_C88308.html
U2 | 1 | STM32F446RETx |  |  |  | beepyRcBrd:LQFP-64_10x10mm_P0.5mm | https://www.st.com/resource/en/datasheet/stm32f446re.pdf
U3 | 1 | INA139 |  |  |  | beepyRcBrd:SOT-23-5 | http://www.ti.com/lit/ds/symlink/ina169.pdf
U4 | 1 | TPS564242DRLR |  |  |  | beepyRcBrd:SOT-5X3-6_W1.6-L1.2-P0.50-LS1.6-BL
U5 | 1 | MC33275ST-3.3T3G |  |  |  | beepyRcBrd:SOT-223_L6.5-W3.5-P2.30-LS7.0-BR | https://lcsc.com/product-detail/Low-Dropout-Regulators-LDO_ON_MC33275ST-3-3T3G_MC33275ST-3-3T3G_C153747.html
U9 | 1 | TLV1117-33 |  |  |  | beepyRcBrd:SOT-223_L6.5-W3.5-P2.30-LS7.0-BR | http://www.ti.com/lit/ds/symlink/tlv1117.pdf
U10 | 1 | CD4011BM96 |  |  |  | beepyRcBrd:SOIC-14_L8.7-W3.9-P1.27-LS6.0-BL | https://lcsc.com/product-detail/4000-Series_TI_CD4011BM96_CD4011BM96_C48466.html
U11 | 1 | AT25SF161B-SSHB-T |  |  |  | beepyRcBrd:SOP-8_L4.9-W3.9-P1.27-LS6.0-BL
U12 | 1 | AT7456ELAH_C42388749 |  |  |  | beepyRcBrd:LGA-16_L6.8-W4.0-P0.65-TL-2EP
X2 | 1 | H6OEL89CSC-SUGYLC-27M |  |  |  | beepyRcBrd:HC-49S_L11.4-W4.8-LS12.7
Y3 | 1 | HY8M49SSMDOB2R20 |  |  |  | beepyRcBrd:CRYSTAL-SMD_L11.4-W4.7-LS12.7 | ~
Y4 | 1 | M332768DWNAC |  |  |  | beepyRcBrd:OSC-SMD_2P-L7.4-W3.1-LS8.0 | ~

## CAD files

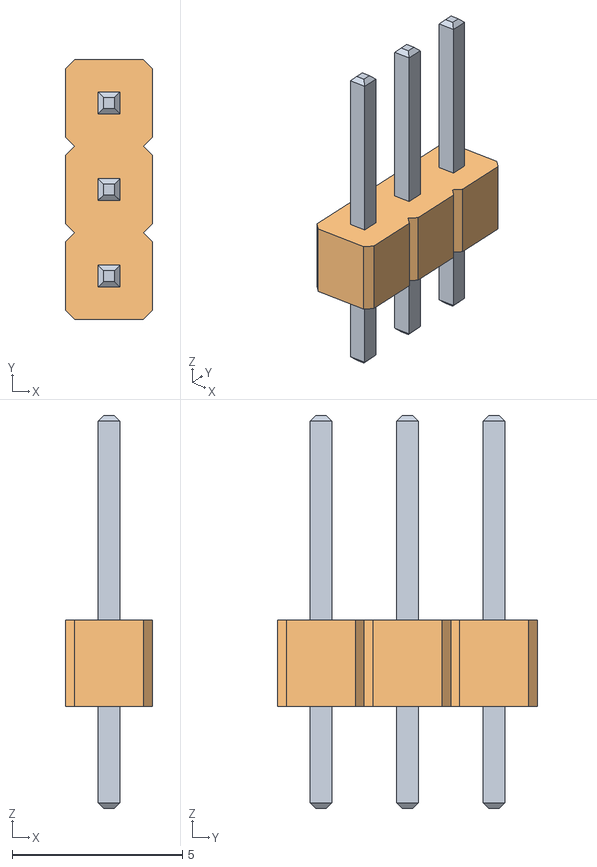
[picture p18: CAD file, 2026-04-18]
hardware/docs/models/ImageToStl.com_PinHeader_1x03_P2.54mm_Vertical/PinHeader_1x03_P2.54mm_Vertical.obj
2.54 x 7.62 x 11.5
obj1
obj2

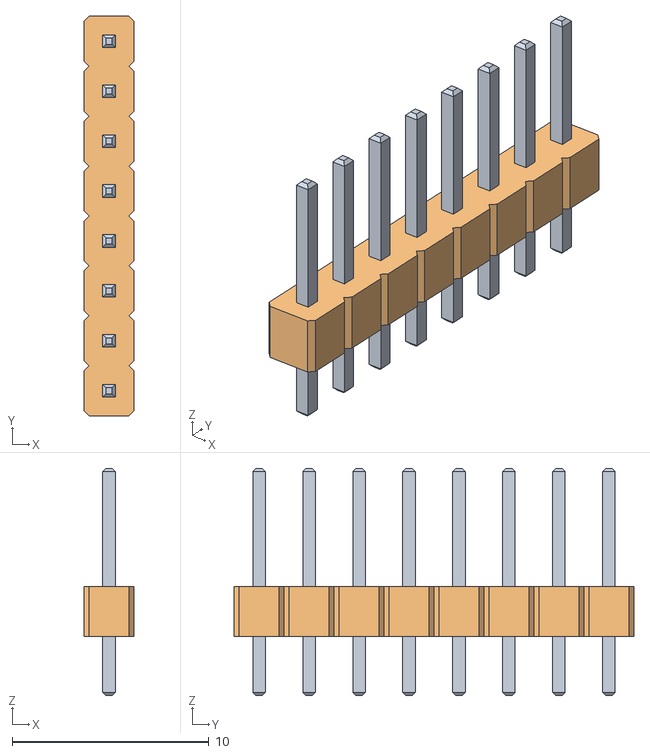
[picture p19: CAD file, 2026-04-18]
hardware/docs/models/ImageToStl.com_PinHeader_1x08_P2.54mm_Vertical/PinHeader_1x08_P2.54mm_Vertical.obj
2.54 x 20.3 x 11.5
obj1
obj2

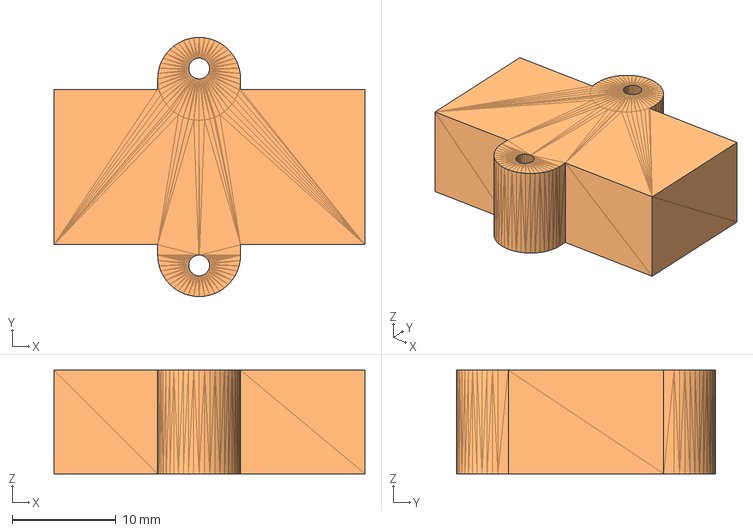
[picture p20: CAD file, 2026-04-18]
hardware/docs/models/Motor.step
30.0 x 25.0 x 10.0 mm

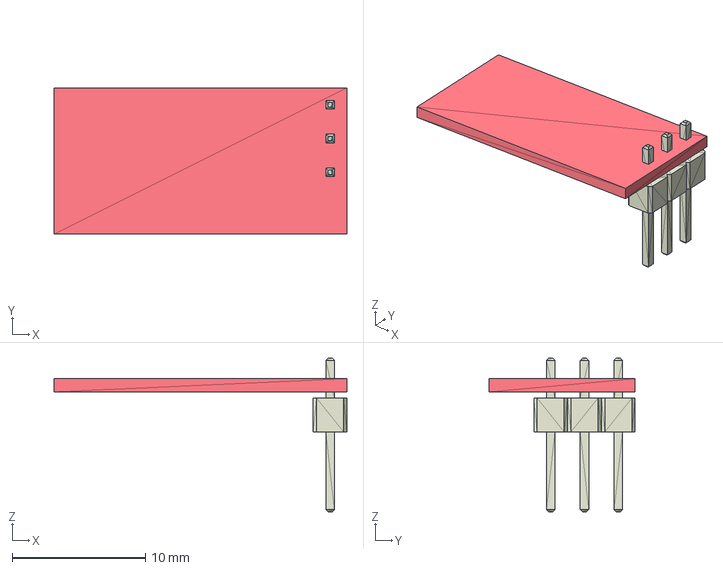
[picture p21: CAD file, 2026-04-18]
hardware/docs/models/rx.step
22.0 x 11.0 x 11.5 mm

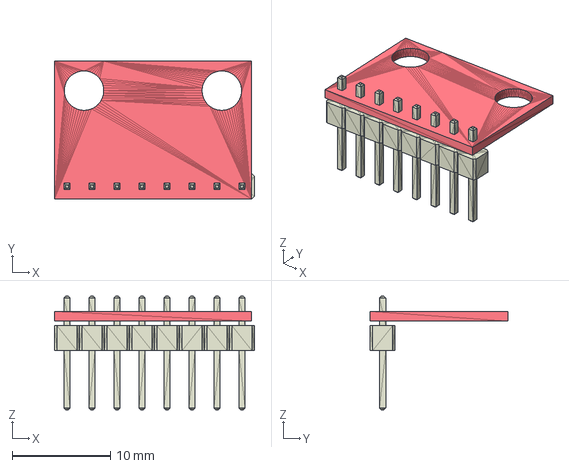
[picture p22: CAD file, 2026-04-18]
hardware/docs/models/GY-91_2.step
20.3 x 14.0 x 11.5 mm

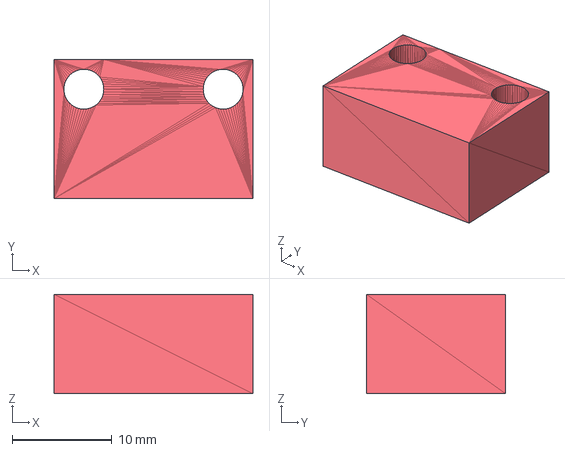
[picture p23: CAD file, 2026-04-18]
hardware/docs/models/GY-91.step
20.0 x 14.0 x 10.0 mm

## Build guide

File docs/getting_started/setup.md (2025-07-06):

# Setup Guide
This project uses the standard STM development environment with STM32CubeProgrammer, STM32CubeMX and STM32CubeIDE.

## Installation

To install the required components follow the guide below:

* [guide](https://medium.com/@erbo-engineering/using-vs-code-for-embedded-stm32-development-14405ed4ac82)

Summary of the overall process:

* Control version and terminal for windows:
    * [Git](https://git-scm.com/downloads) (for windows install git bash).
* Tool to program the STM32 microcontroller:
    * Download [STM32CubeProgrammer](https://www.st.com/en/development-tools/stm32cubeprog.html)
    * Option 1: Add it to the path environment variable as: <install-path>\STM32Cube\STM32CubeProgrammer\bin.
    * Option 2: In the Makefile update the __STLINK_TOOLCHAIN_PATH__ symbol with your installation path.
* (optional) ST tool for MCU pin assignment and automatic code initialization
    * [STM32CubeMX](https://www.st.com/en/development-tools/stm32cubemx.html).
    * It is better to maintain a separate project with with the cubeMX code to check the peripheral configurations and initialization procedure.
* Debugging on STM32 with GDB:
    * Install [STM32CubeIDE](https://www.st.com/en/development-tools/stm32cubeide.html). Note, this program is just needed to get the STLink GDB Server (there may be a better way to obtain it).
    * Once installed, the GDB Server path needs to be used in the launch.json (check below for further info): ```STM32CubeIDE_1.18.1\STM32CubeIDE\plugins\com.st.stm32cube.ide.mcu.externaltools.stlink-gdb-server.win32_2.2.100.202501151542\tools\bin\ST-LINK_gdbserver.exe```
* Cross compiler:
    * [gcc-arm-none-eabi](https://developer.arm.com/downloads/-/gnu-rm)
    * Option 1: Add it to the path environment variable as: <install-path>\Arm GNU Toolchain arm-none-eabi\14.2 rel1\bin.
    * Option 2: Modify the __ARM_TOOLCHAIN_PATH__ symbol in the makefile with the toolchain path.
* Makefile:
    * [GnuWin32](https://gnuwin32.sourceforge.net/packages/make.htm)

## Compile, Flash and Debug the Firmware
All the compilation is done using the Git Bash terminal, to maintain compatibility with other environments.

On VS code, on the terminal screen, the down arrow next to the '+' symbol should display the terminal options. Select Git Bash.

Navigate to the following directory:
```bash
cd firmware/make
```
Then to perform a clean compilation + flashing the MCU + monitoring the debug interface run:
```bash
make clean && make all && make flash && make monitor
```

Faster compilation can be done adding more jobs:
```bash
make all -j3
```

## Debug with GDB

### Setting up
Debugging with GDB enables you to stop the code execution at different points; run the code line by line; check the call stack at any point in the code; monitor variables and registers during the code excution; alongside other invaluable tools. This is a much better option that the infamous _printf debugging_ approach.

Setting VS code to support is relatively straight forward:

1. Install the [Cortex-Debug](https://marketplace.visualstudio.com/items?itemName=marus25.cortex-debug) plugin in VS code.
2. Create the launch.json configuration file by:
    * On the VS code at the left of the screen, select the __Run & Debug__ tab.
    * If you do not have the _launch.json_ file created, there should be an option to create it. Otherwise open the launch.json file.
    * Copy the code from bellow adjusting the values within __<>__

```
{
    // Use IntelliSense to learn about possible attributes.
    // Hover to view descriptions of existing attributes.
    // For more information, visit: https://go.microsoft.com/fwlink/?linkid=830387
    "version": "0.2.0",
    "configurations": [
        {
            "name": "Cortex ST-Link",
            "cwd": "${workspaceRoot}",
            "executable": <1 - project.elf>,
            "request": "launch",
            "type": "cortex-debug",
            "servertype": "stlink",
            "stlinkPath": <2 - ST-LINK_gdbserver.exe>,
            "stm32cubeprogrammer": <3 - STM32CubeProgrammer>,
            "device": "STM32F446RET6",
            "svdFile": "./firmware/lib/mcu/stm32f446x/STM32F446.svd",
            "runToEntryPoint": "main",
            "showDevDebugOutput": true,
            "interface": "swd",
            "armToolchainPath": "Arm GNU Toolchain arm-none-eabi",
        },
    ]
}
```

Things to replace:

1. This is the relative path from the project's root to the __.elf__ file generated after compiling. For this project ```"./firmware/make/bin/beepy_rc.elf"```
2. This is the path to the ST-LINK_gdbserver.exe file, which should be installed as part of the CubeIDE installation. ```"<installation path>\bin\ST-LINK_gdbserver.exe"```
3. This is the path of the STM32CubeProgrammer's bin directory. ```"<install path>\\STMicroelectronics\\STM32Cube\\STM32CubeProgrammer\\bin"```
4. This is the path to the Arm tool chain's bin directory. ```<install path>\\Arm GNU Toolchain arm-none-eabi\\14.2 rel1\\bin"```

### Debug
To run create a GDB debugging session first ensure that the .elf file has been generated using the debug flags
```
CFLAGS += -g -gdwarf-2
```
Ensure that the board is connected through the ST-link, in the Nucleo board this is the USB in the board.

Then on VS code select the __Run and Debug__ tab on the left menu, followed by start debugging. Note that you should have selected the "Cortex ST-Link" configuration created earlier.
This should created the GDB session stopping the execution in the main function. From this point on it should work just as any other GDB session.

## Intellisense
The Intellisense manages the code completing code checking in the IDE. In VSCode is configured through the c_cpp_properties.json file.
A key aspect to configure the Intellisense is to give it the paths of the files that compose the project, so it can extract the names of the valid symbols, variables, defines, etc.

The project's dependencies can be extracted directly from the makefile using [compiledb](https://github.com/nickdiego/compiledb), which generates a Clang JSON compilation database, which is then used by the IDE's Intellisense.

Install _compiledb_
```
python -m pip install compiledb
```

Generate the compile_commands.json, this needs to be done now and then to ensure it remains updated.
```
cd firmware/make
python -m compiledb make all
mv compile_commands.json ../../.vscode/compile_commands.json
```

Then, configure VSCode to ensure it uses the compile_commands.json file, by modifying the ```c_cpp_properties.json``` file:
```
{
    "configurations": [
        {
            "name": "Win32",
            "includePath": [
                "${workspaceFolder}/**"
            ],
            "defines": [
                "_DEBUG",
                "UNICODE",
                "_UNICODE"
            ],
            "windowsSdkVersion": "10.0.22621.0",
            "compilerPath": "1 - Arm GNU Toolchain arm-none-eabi",
            "cStandard": "c17",
            "cppStandard": "c++17",
            "intelliSenseMode": "windows-gcc-x86",
            "compileCommands": "${workspaceFolder}/.vscode/compile_commands.json"
        }
    ],
    "version": 4
}
```
1. This is the path to the Arm tool chain's bin directory. ```<install path>\\Arm GNU Toolchain arm-none-eabi\\14.2 rel1\\bin"```

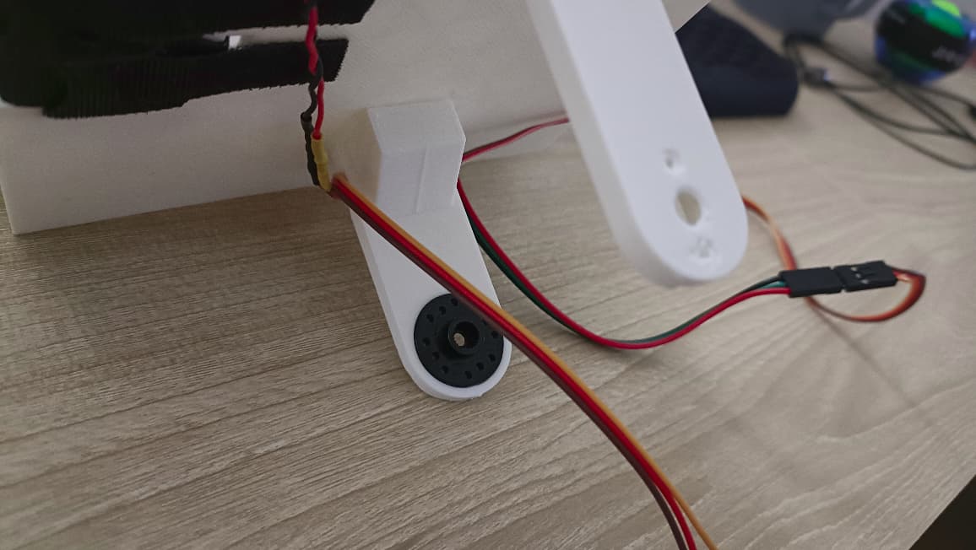
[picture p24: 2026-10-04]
docs/imgs/mech_step_6.jpg

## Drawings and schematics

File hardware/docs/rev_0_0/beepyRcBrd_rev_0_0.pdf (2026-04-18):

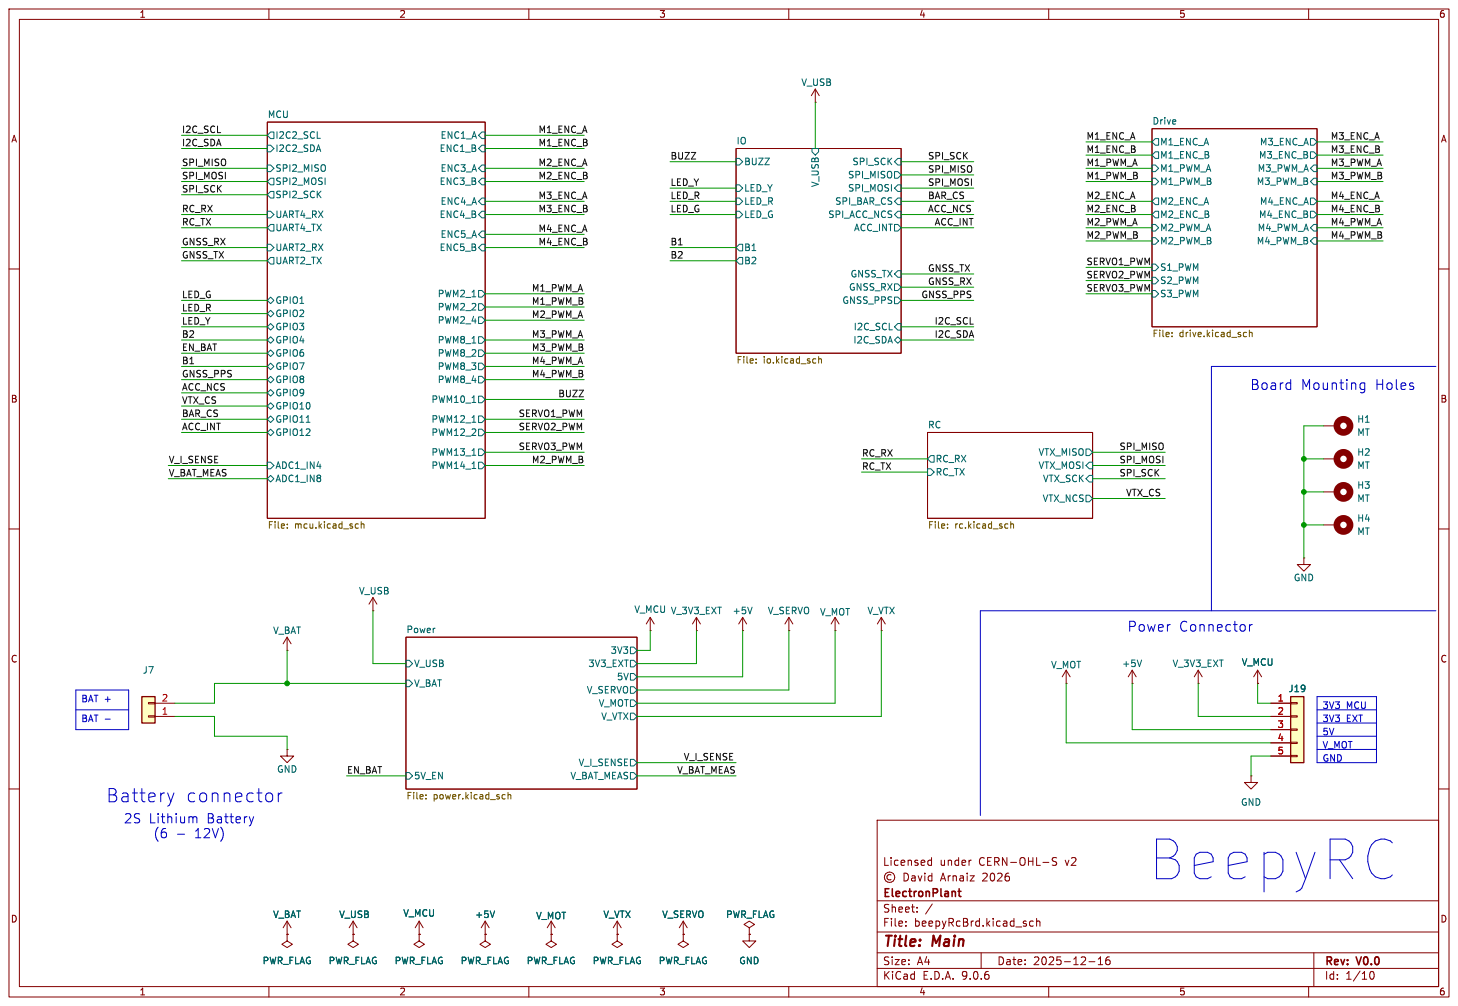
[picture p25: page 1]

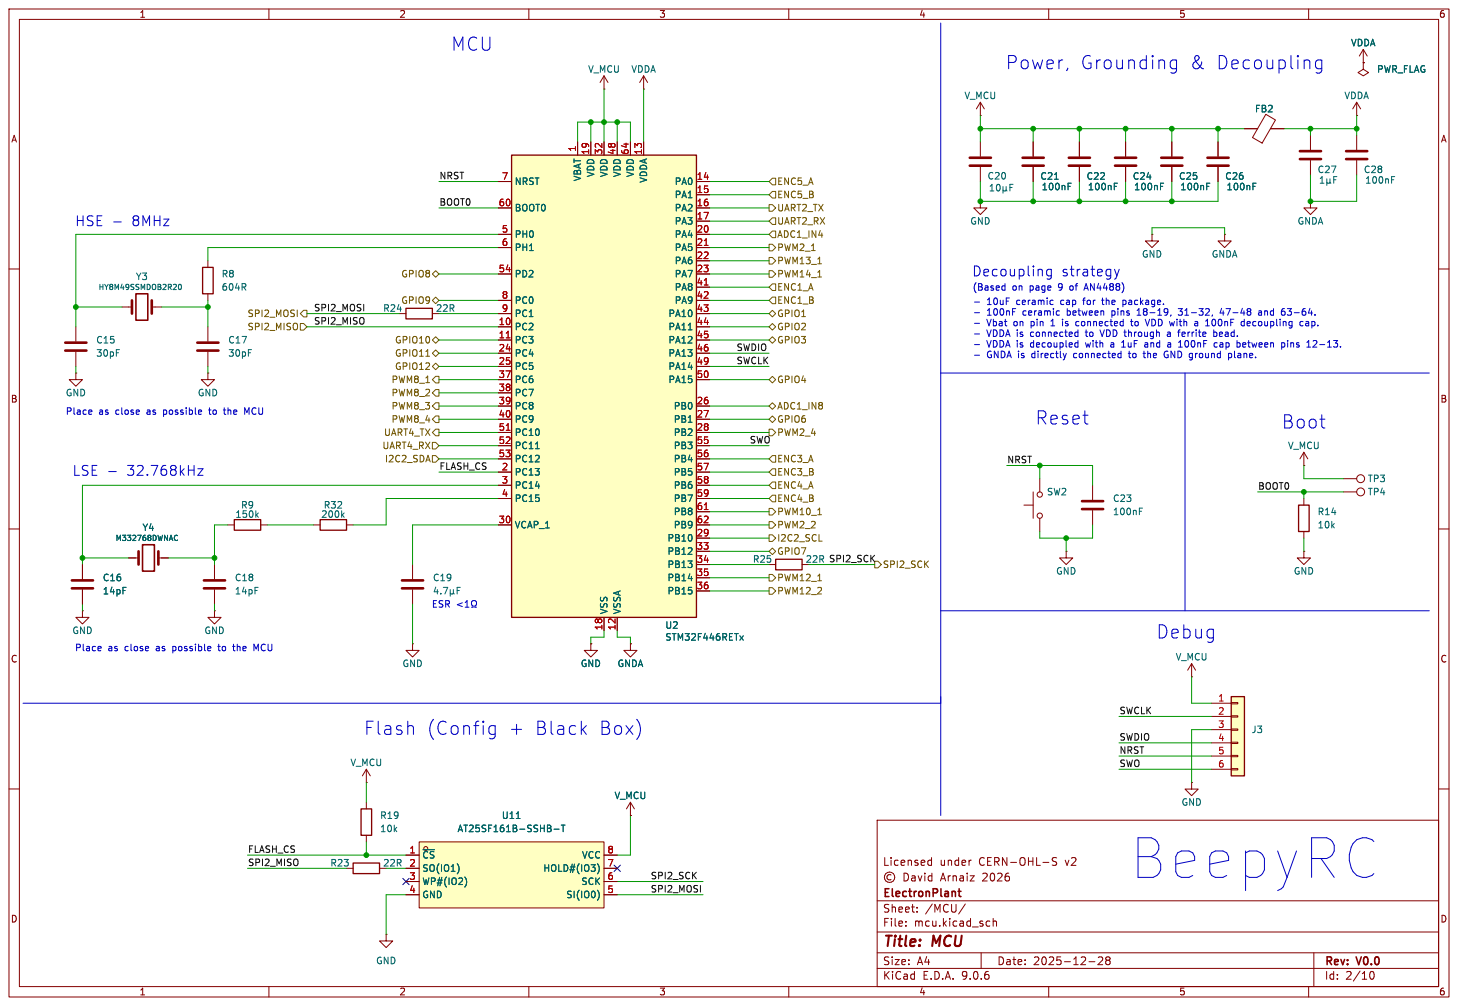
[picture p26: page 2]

1 VDD 19 VDD 32 VSS 18 VDD 48 VSSA 12 VDD 64 VDDA 13 PA0 14 PA1 15 PA2 16 PA3 17 PA4 20 PA5 21 PA6 22 PA7 23 PA8 41 PA9 42 PA10 43 PA11 44 PA12 45 PA13 46 PA14 49 PA15 50 PB0 26 PB1 27 PB2 28 PB3 55 PB4 56 PB5 57 PB6 58 PB7 59 PB8 61 PB9 62 PB10 29 PB12 33 PB13 34 PB14 35 PB15 36 U2STM32F446RETx GND

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

(Based on page 9 of AN4488)

Flash (Config + Black Box)

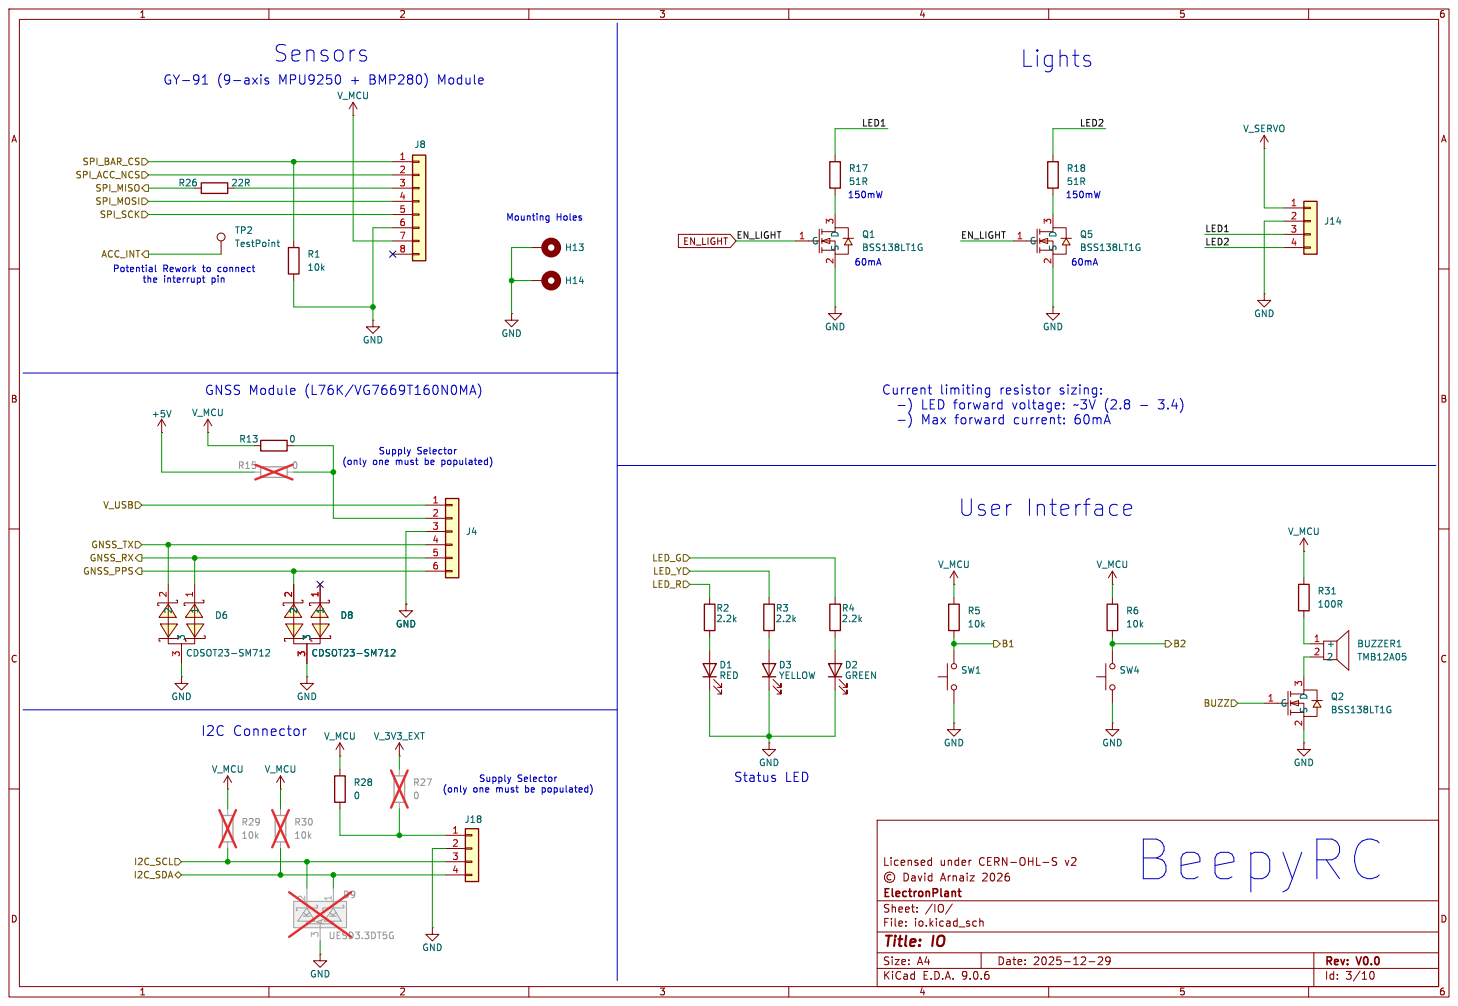
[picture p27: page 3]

(only one must be populated)

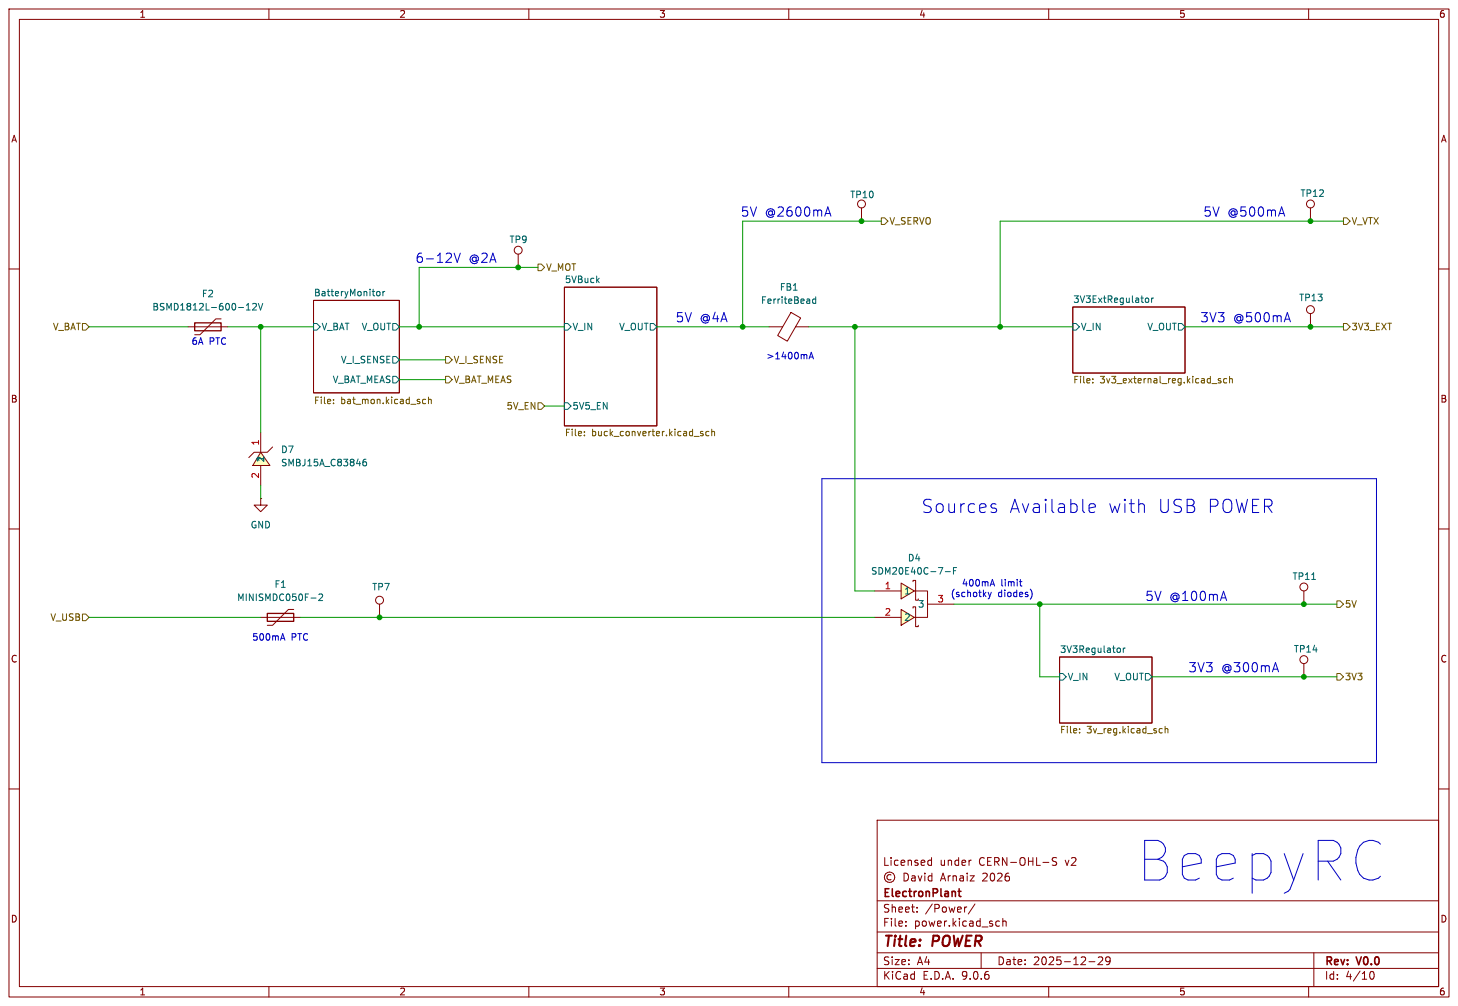
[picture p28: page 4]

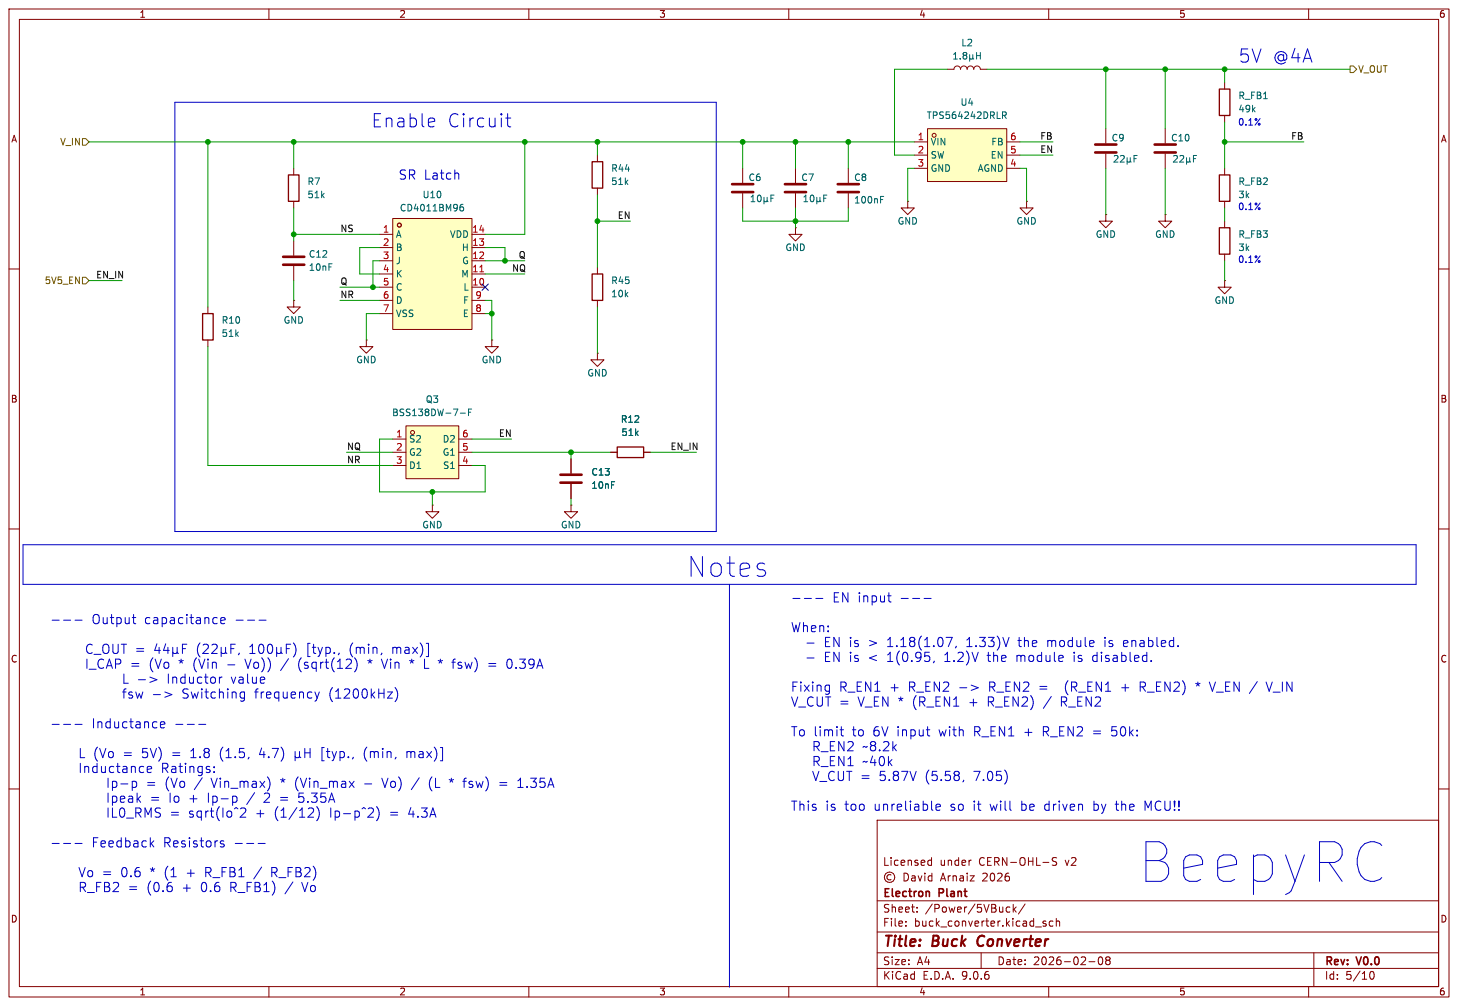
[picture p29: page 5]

Ip-p = (Vo / Vin_max) * (Vin_max - Vo) / (L * fsw) = 1.35A
Ipeak = Io + Ip-p / 2 = 5.35A

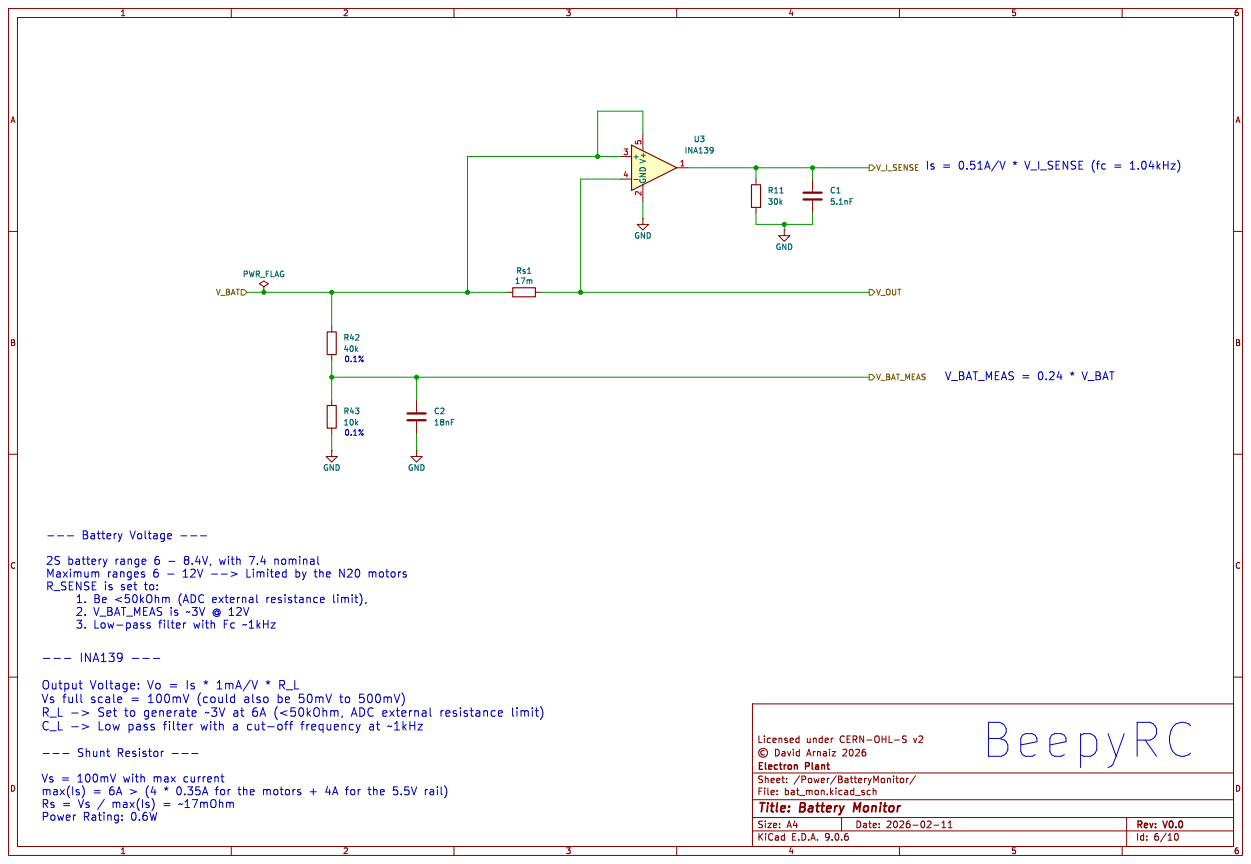
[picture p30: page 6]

max(Is) = 6A > (4 * 0.35A for the motors + 4A for the 5.5V rail)
Rs = Vs / max(Is) = ~17mOhm
Power Rating: 0.6W

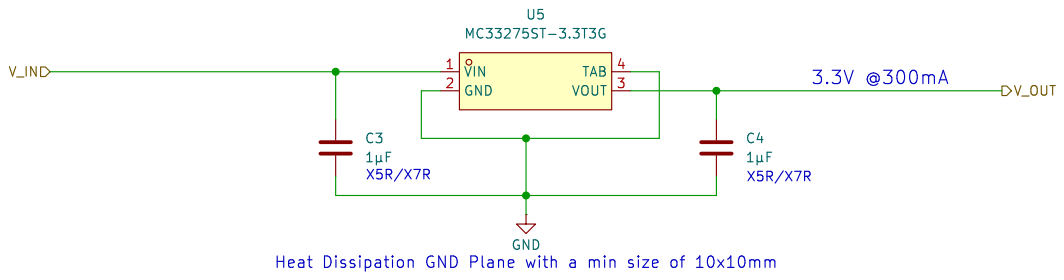
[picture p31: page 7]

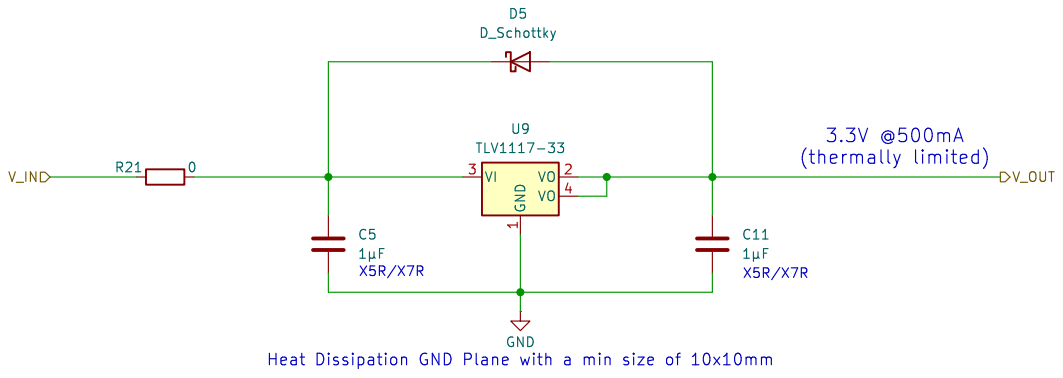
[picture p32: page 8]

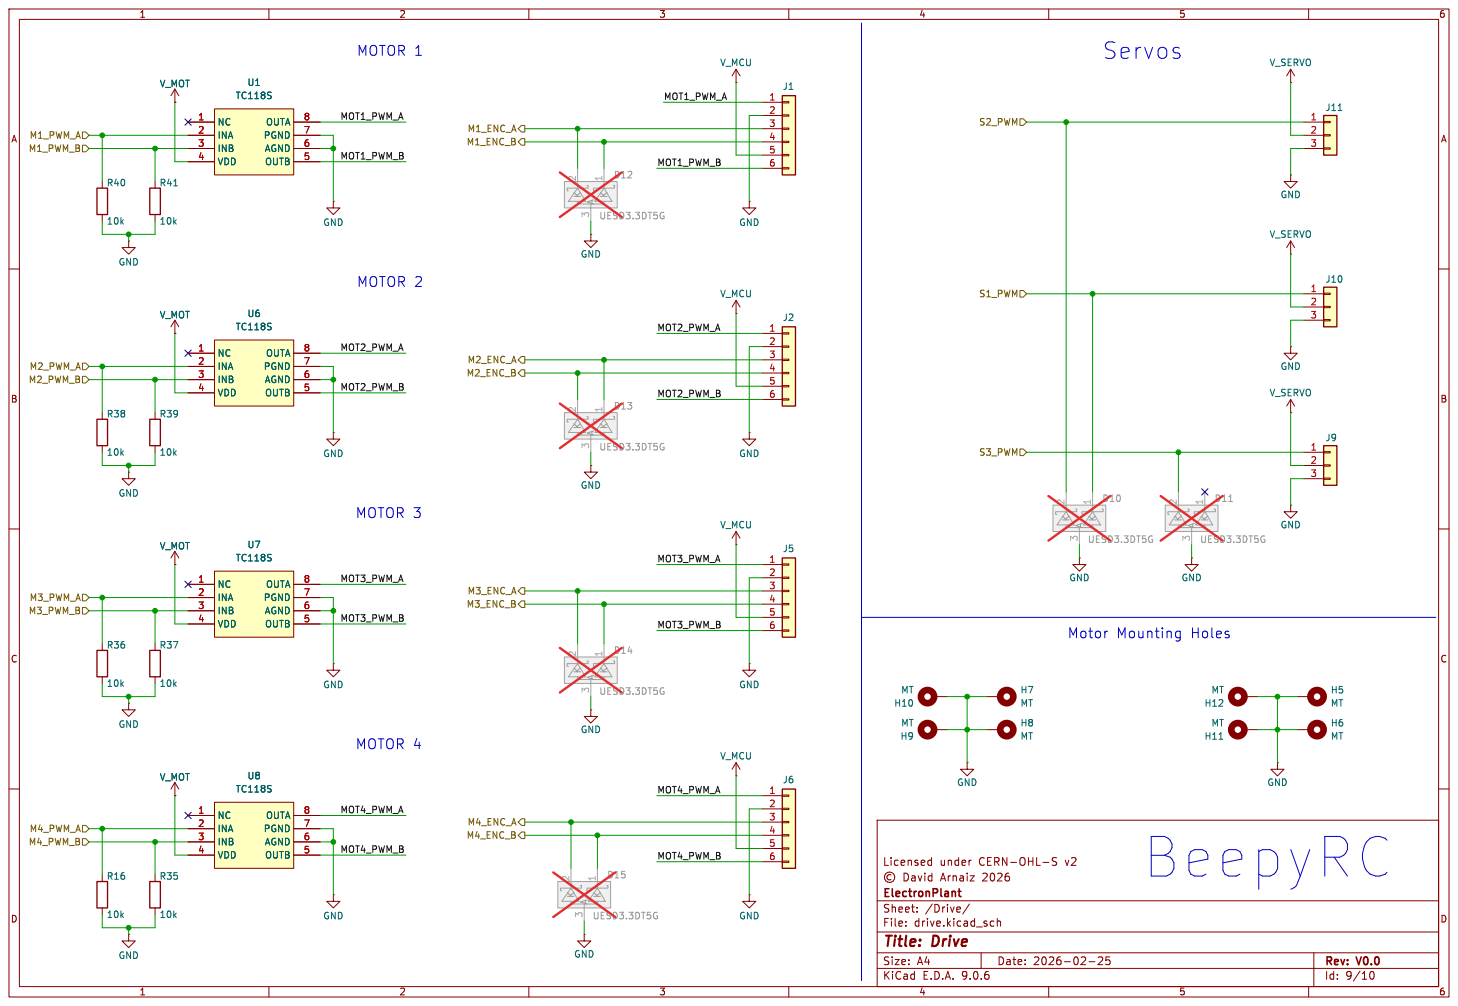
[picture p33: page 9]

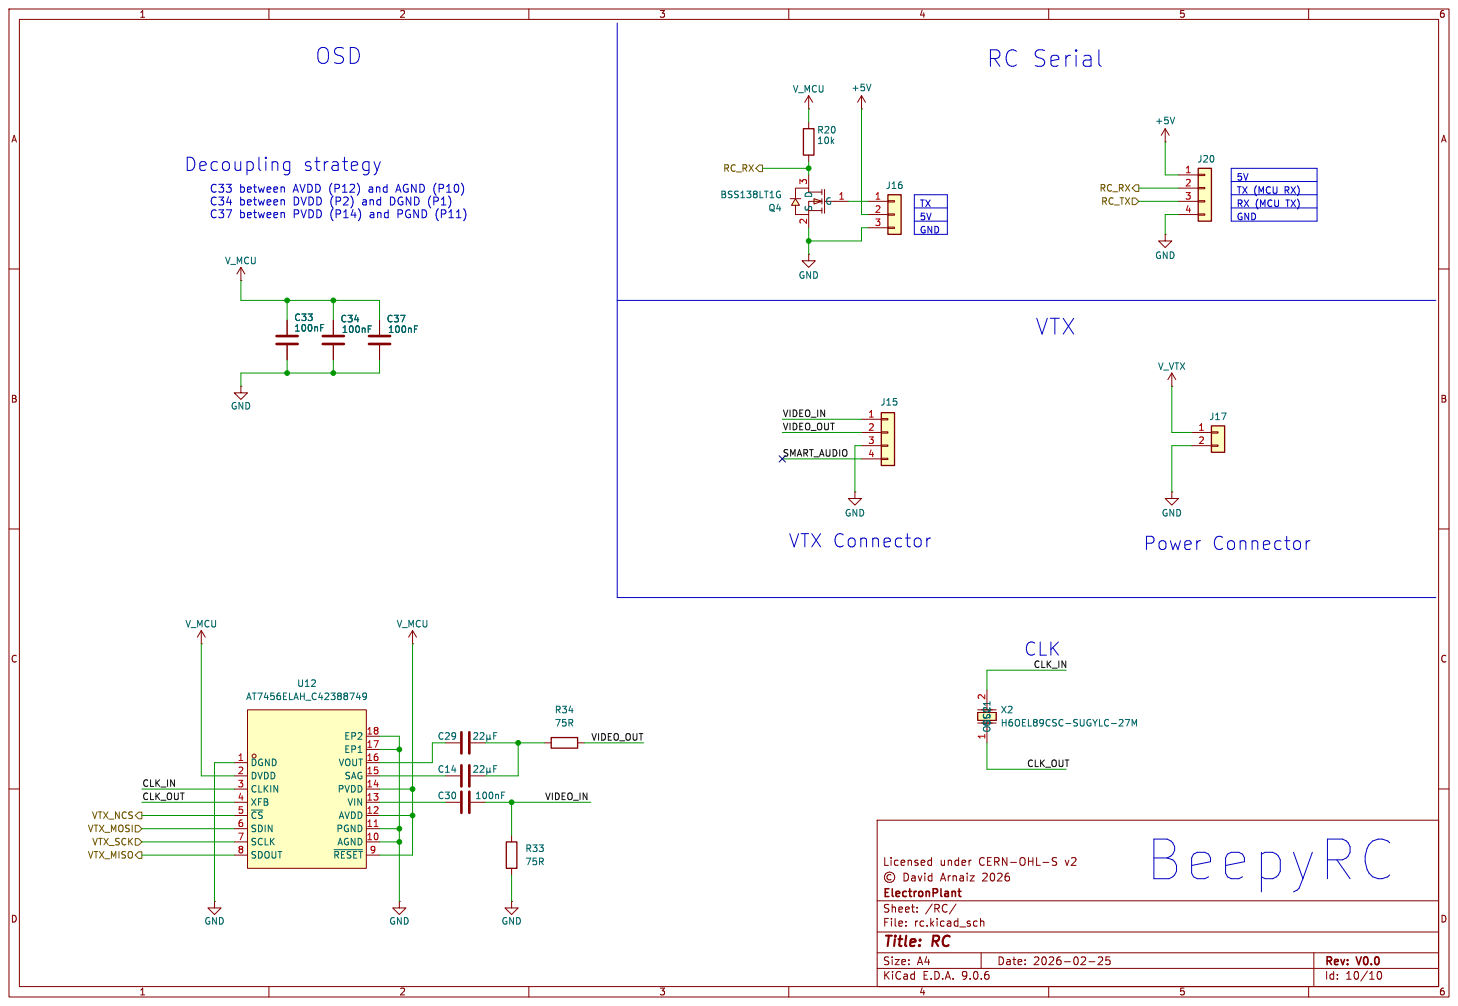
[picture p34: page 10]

J16 GND
C33 between AVDD (P12) and AGND (P10)
C34 between DVDD (P2) and DGND (P1)
C37 between PVDD (P14) and PGND (P11) C33

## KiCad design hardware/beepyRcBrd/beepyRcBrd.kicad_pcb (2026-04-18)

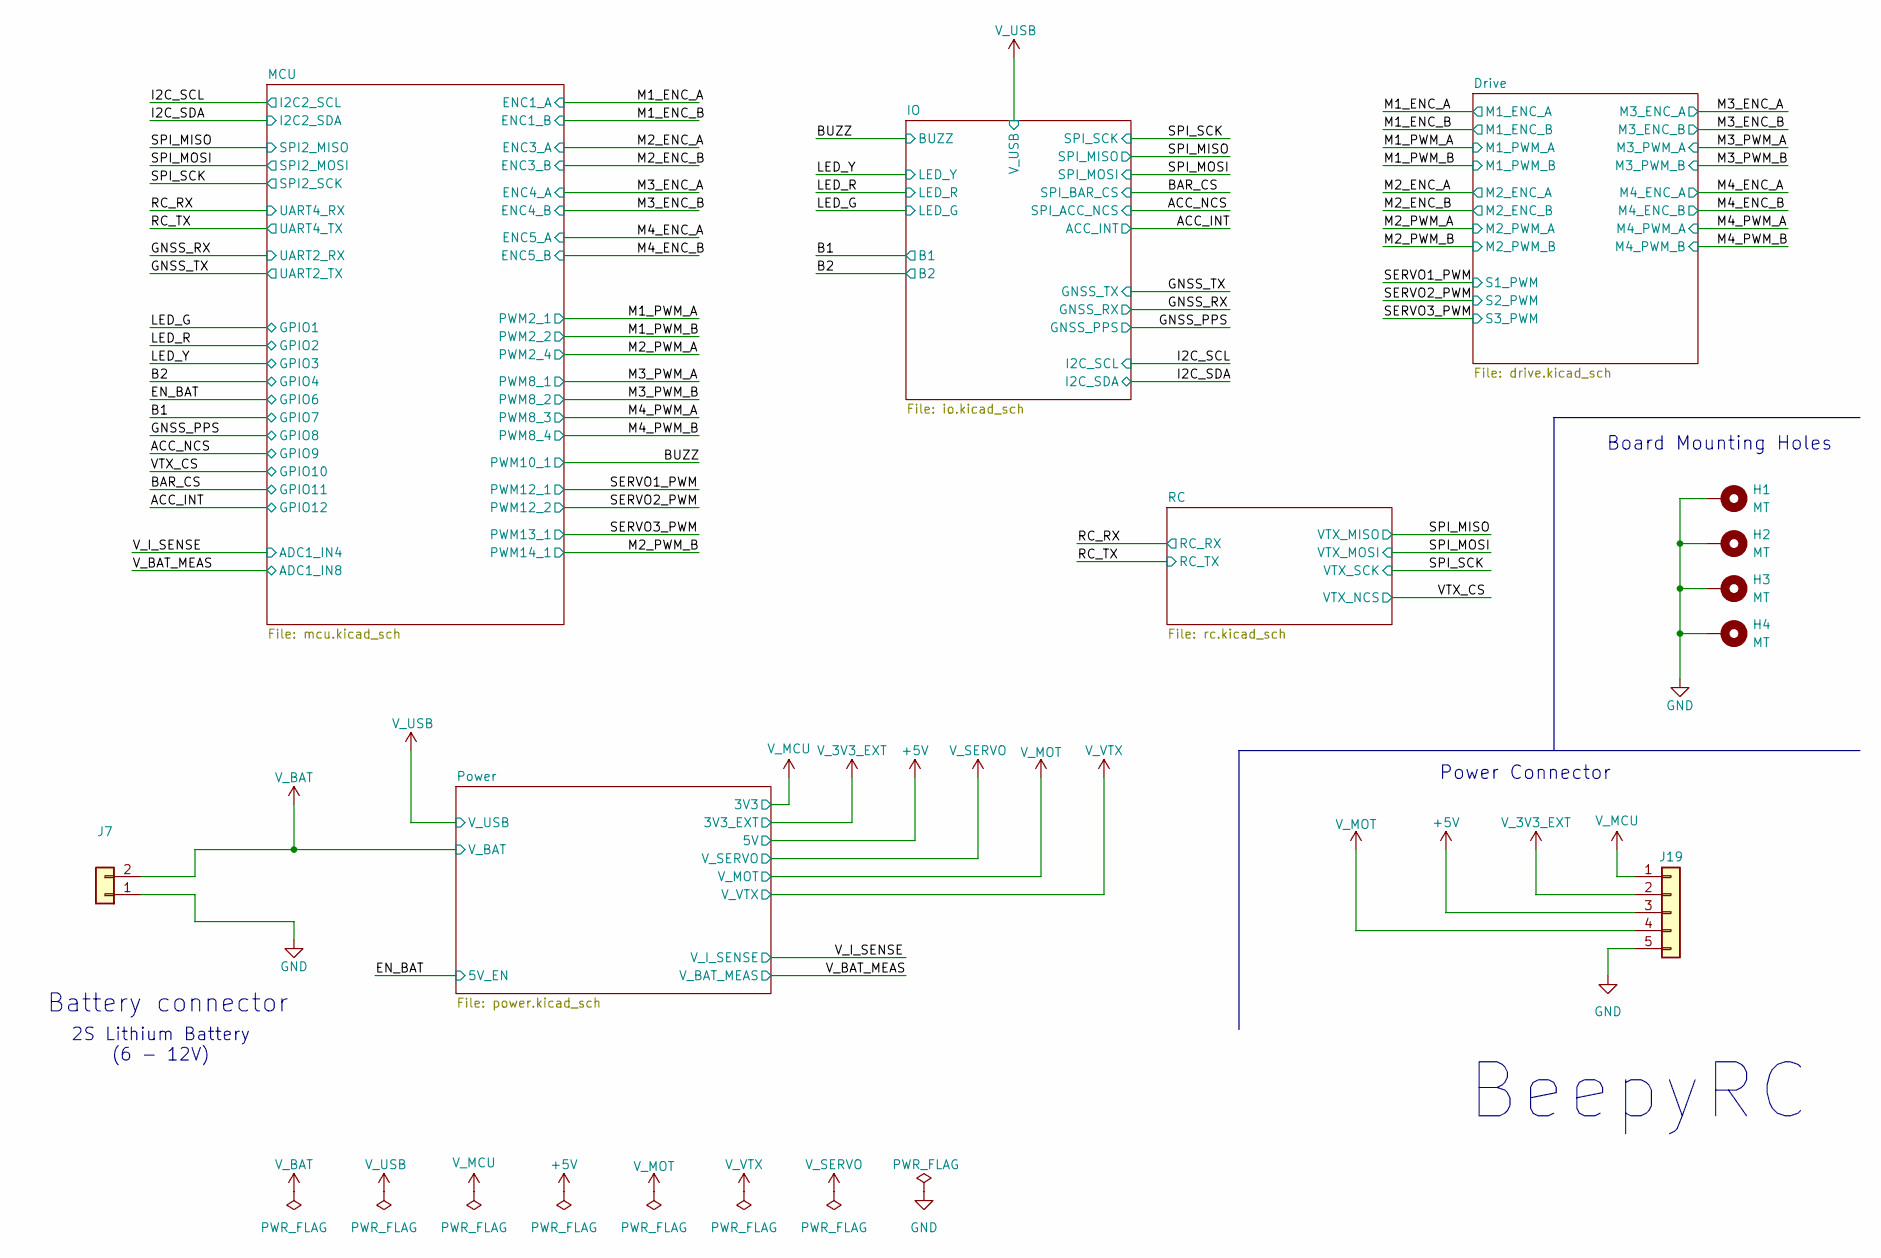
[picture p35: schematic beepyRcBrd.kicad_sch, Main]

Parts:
H1, H2, H3, H4: MT; MountingHole_4.3mm_M4_DIN965_Pad_TopBottom
J7: Conn_01x02; CONN-TH_P5.00_KF301-5.0-2P
J19: Conn_01x05; CONN-TH_5P-P3.50_DORABO_DB125-3.5-5P-GN-S

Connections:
+5V: J19.3; also elsewhere on the board
GND: H1.1, H2.1, H3.1, H4.1, J7.1, J19.5; also elsewhere on the board
V_3V3_EXT: J19.2; also elsewhere on the board
V_BAT: J7.2; also elsewhere on the board
V_MCU: J19.1; also elsewhere on the board
V_MOT: J19.4; also elsewhere on the board

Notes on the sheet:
Battery connector
2S Lithium Battery (6 - 12V)
Power Connector
BeepyRC
Board Mounting Holes

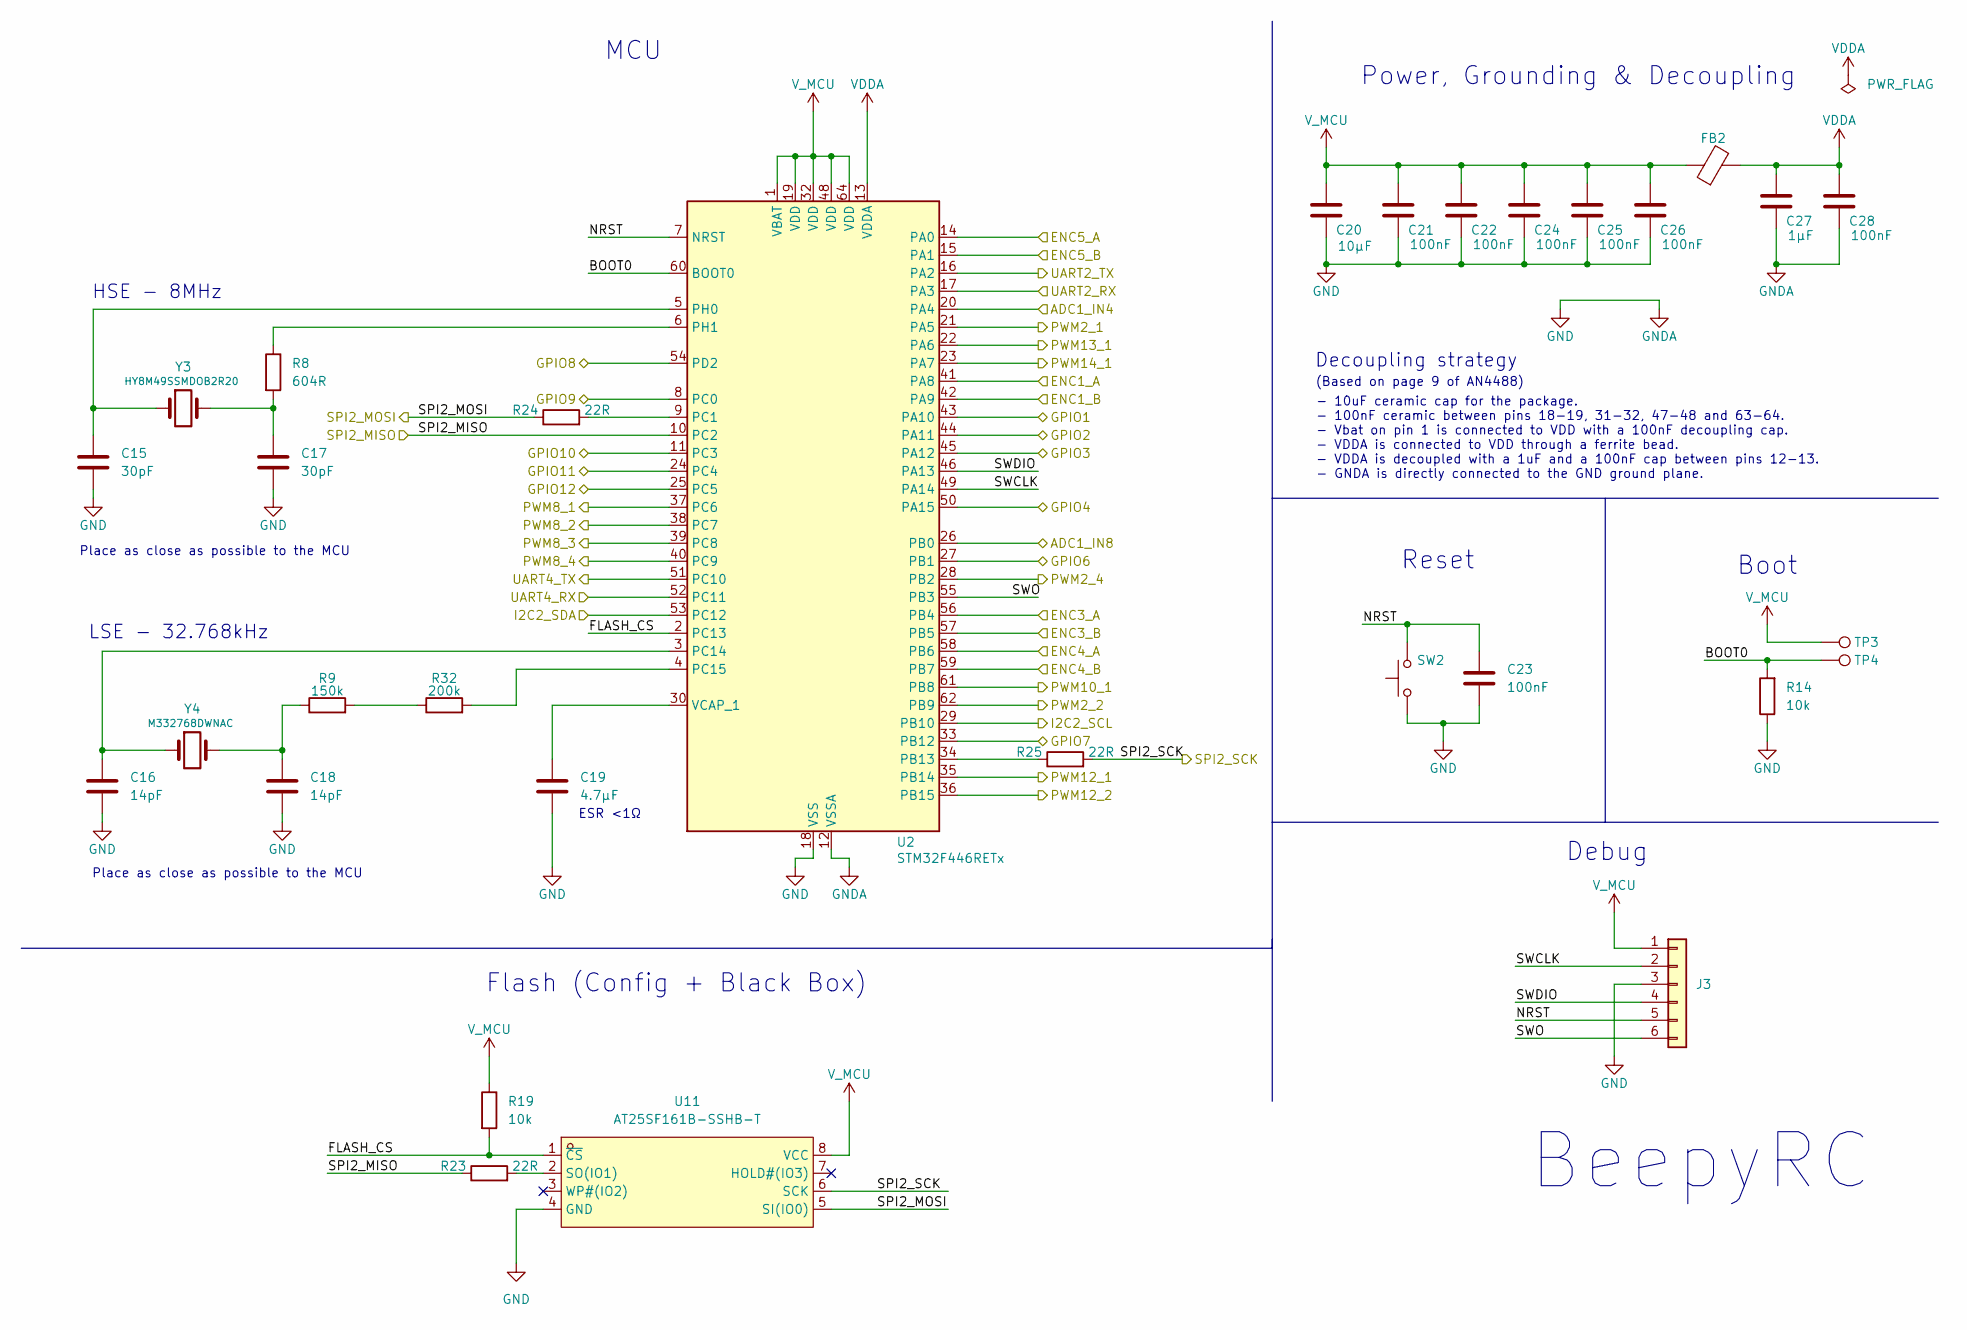
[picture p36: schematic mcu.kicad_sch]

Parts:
C15, C17: 30pF; C_0603_1608Metric_Pad1.08x0.95mm_HandSolder
C16, C18: 14pF; C_0603_1608Metric_Pad1.08x0.95mm_HandSolder
C19: 4.7μF; C_0603_1608Metric_Pad1.08x0.95mm_HandSolder
C20: 10μF; C_0603_1608Metric_Pad1.08x0.95mm_HandSolder
C21, C22, C23, C24, C25, C26, C28: 100nF; C_0603_1608Metric_Pad1.08x0.95mm_HandSolder
C27: 1μF; C_0603_1608Metric_Pad1.08x0.95mm_HandSolder
FB2: FerriteBead; R_0603_1608Metric_Pad0.98x0.95mm_HandSolder
J3: Conn_01x06; PinHeader_1x06_P2.54mm_Vertical
R8: 604R; R_0603_1608Metric_Pad0.98x0.95mm_HandSolder
R9: 150k; R_0603_1608Metric_Pad0.98x0.95mm_HandSolder
R14, R19: 10k; R_0603_1608Metric_Pad0.98x0.95mm_HandSolder
R23, R24, R25: 22R; R_0603_1608Metric_Pad0.98x0.95mm_HandSolder
R32: 200k; R_0603_1608Metric_Pad0.98x0.95mm_HandSolder
SW2: SW_Push; SW-SMD_L3.9-W3.0-P4.45
TP3, TP4: TestPoint; TestPoint_Pad_D1.0mm
U2: STM32F446RETx; LQFP-64_10x10mm_P0.5mm
U11: AT25SF161B-SSHB-T; SOP-8_L4.9-W3.9-P1.27-LS6.0-BL; LCSC Part C5555631
Y3: HY8M49SSMDOB2R20; CRYSTAL-SMD_L11.4-W4.7-LS12.7
Y4: M332768DWNAC; OSC-SMD_2P-L7.4-W3.1-LS8.0

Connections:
/ACC_INT: U2.25 (PC5); also elsewhere on the board
/ACC_NCS: U2.8 (PC0); also elsewhere on the board
/B1: U2.33 (PB12); also elsewhere on the board
/B2: U2.50 (PA15); also elsewhere on the board
/BAR_CS: U2.24 (PC4); also elsewhere on the board
/BUZZ: U2.61 (PB8); also elsewhere on the board
/EN_BAT: U2.27 (PB1); also elsewhere on the board
/GNSS_PPS: U2.54 (PD2); also elsewhere on the board
/GNSS_RX: U2.17 (PA3); also elsewhere on the board
/GNSS_TX: U2.16 (PA2); also elsewhere on the board
/I2C_SCL: U2.29 (PB10); also elsewhere on the board
/I2C_SDA: U2.53 (PC12); also elsewhere on the board
/LED_G: U2.43 (PA10); also elsewhere on the board
/LED_R: U2.44 (PA11); also elsewhere on the board
/LED_Y: U2.45 (PA12); also elsewhere on the board
/M1_ENC_A: U2.41 (PA8); also elsewhere on the board
/M1_ENC_B: U2.42 (PA9); also elsewhere on the board
/M1_PWM_A: U2.21 (PA5); also elsewhere on the board
/M1_PWM_B: U2.62 (PB9); also elsewhere on the board
/M2_ENC_A: U2.56 (PB4); also elsewhere on the board
/M2_ENC_B: U2.57 (PB5); also elsewhere on the board
/M2_PWM_A: U2.28 (PB2); also elsewhere on the board
/M2_PWM_B: U2.23 (PA7); also elsewhere on the board
/M3_ENC_A: U2.58 (PB6); also elsewhere on the board
/M3_ENC_B: U2.59 (PB7); also elsewhere on the board
/M3_PWM_A: U2.37 (PC6); also elsewhere on the board
/M3_PWM_B: U2.38 (PC7); also elsewhere on the board
/M4_ENC_A: U2.14 (PA0); also elsewhere on the board
/M4_ENC_B: U2.15 (PA1); also elsewhere on the board
/M4_PWM_A: U2.39 (PC8); also elsewhere on the board
/M4_PWM_B: U2.40 (PC9); also elsewhere on the board
/MCU/BOOT0: R14.2, TP4.1, U2.60 (BOOT0)
/MCU/FLASH_CS: R19.2, U2.2 (PC13), U11.1 (~CS)
/MCU/NRST: C23.1, J3.5, SW2.2, U2.7 (NRST)
/MCU/SWCLK: J3.2, U2.49 (PA14)
/MCU/SWDIO: J3.4, U2.46 (PA13)
/MCU/SWO: J3.6, U2.55 (PB3)
/RC_RX: U2.52 (PC11); also elsewhere on the board
/RC_TX: U2.51 (PC10); also elsewhere on the board
/SERVO1_PWM: U2.35 (PB14); also elsewhere on the board
/SERVO2_PWM: U2.36 (PB15); also elsewhere on the board
/SERVO3_PWM: U2.22 (PA6); also elsewhere on the board
/SPI_MISO: R23.1, U2.10 (PC2); also elsewhere on the board
/SPI_MOSI: R24.1, U11.5 (SI(IO0)); also elsewhere on the board
/SPI_SCK: R25.2, U11.6 (SCK); also elsewhere on the board
/VTX_CS: U2.11 (PC3); also elsewhere on the board
/V_BAT_MEAS: U2.26 (PB0); also elsewhere on the board
/V_I_SENSE: U2.20 (PA4); also elsewhere on the board
GND: C15.2, C16.2, C17.2, C18.2, C19.2, C20.2, C21.2, C22.2, C23.2, C24.2, C25.2, C26.2, C27.2, C28.2, J3.3, R14.1, SW2.1, U2.12 (VSSA), U2.18 (VSS), U2.31 (VSS), U2.47 (VSS), U2.63 (VSS), U11.4 (GND); also elsewhere on the board
unnamed: C17.1, R8.2, Y3.2
unnamed: C18.1, R9.1, Y4.2
unnamed: R9.2, R32.1
unnamed: R25.1, U2.34 (PB13)
unnamed: R24.2, U2.9 (PC1)
unnamed: C16.1, U2.3 (PC14), Y4.1
unnamed: R32.2, U2.4 (PC15)
unnamed: C15.1, U2.5 (PH0), Y3.1
unnamed: R8.1, U2.6 (PH1)
unnamed: C19.1, U2.30 (VCAP_1)
unnamed: R23.2, U11.2 (SO(IO1))
VDDA: C27.1, C28.1, FB2.2, U2.13 (VDDA)
V_MCU: C20.1, C21.1, C22.1, C24.1, C25.1, C26.1, FB2.1, J3.1, R19.1, TP3.1, U2.1 (VBAT), U2.19 (VDD), U2.32 (VDD), U2.48 (VDD), U2.64 (VDD), U11.8 (VCC); also elsewhere on the board

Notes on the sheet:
LSE - 32.768kHz
Decoupling strategy
Place as close as possible to the MCU
Reset
BeepyRC
ESR <1Ω
- 10uF ceramic cap for the package. - 100nF ceramic between pins 18-19, 31-32, 47-48 and 63-64. - Vbat on pin 1 is connected to VDD with a 100nF decoupling cap. - VDDA is connected to VDD through a ferrite bead. - VDDA is decoupled with a 1uF and a 100nF cap between pins 12-13. - GNDA is directly c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
MCU
Flash (Config + Black Box)
(Based on page 9 of AN4488)
Power, Grounding & Decoupling
Boot
HSE - 8MHz
Debug

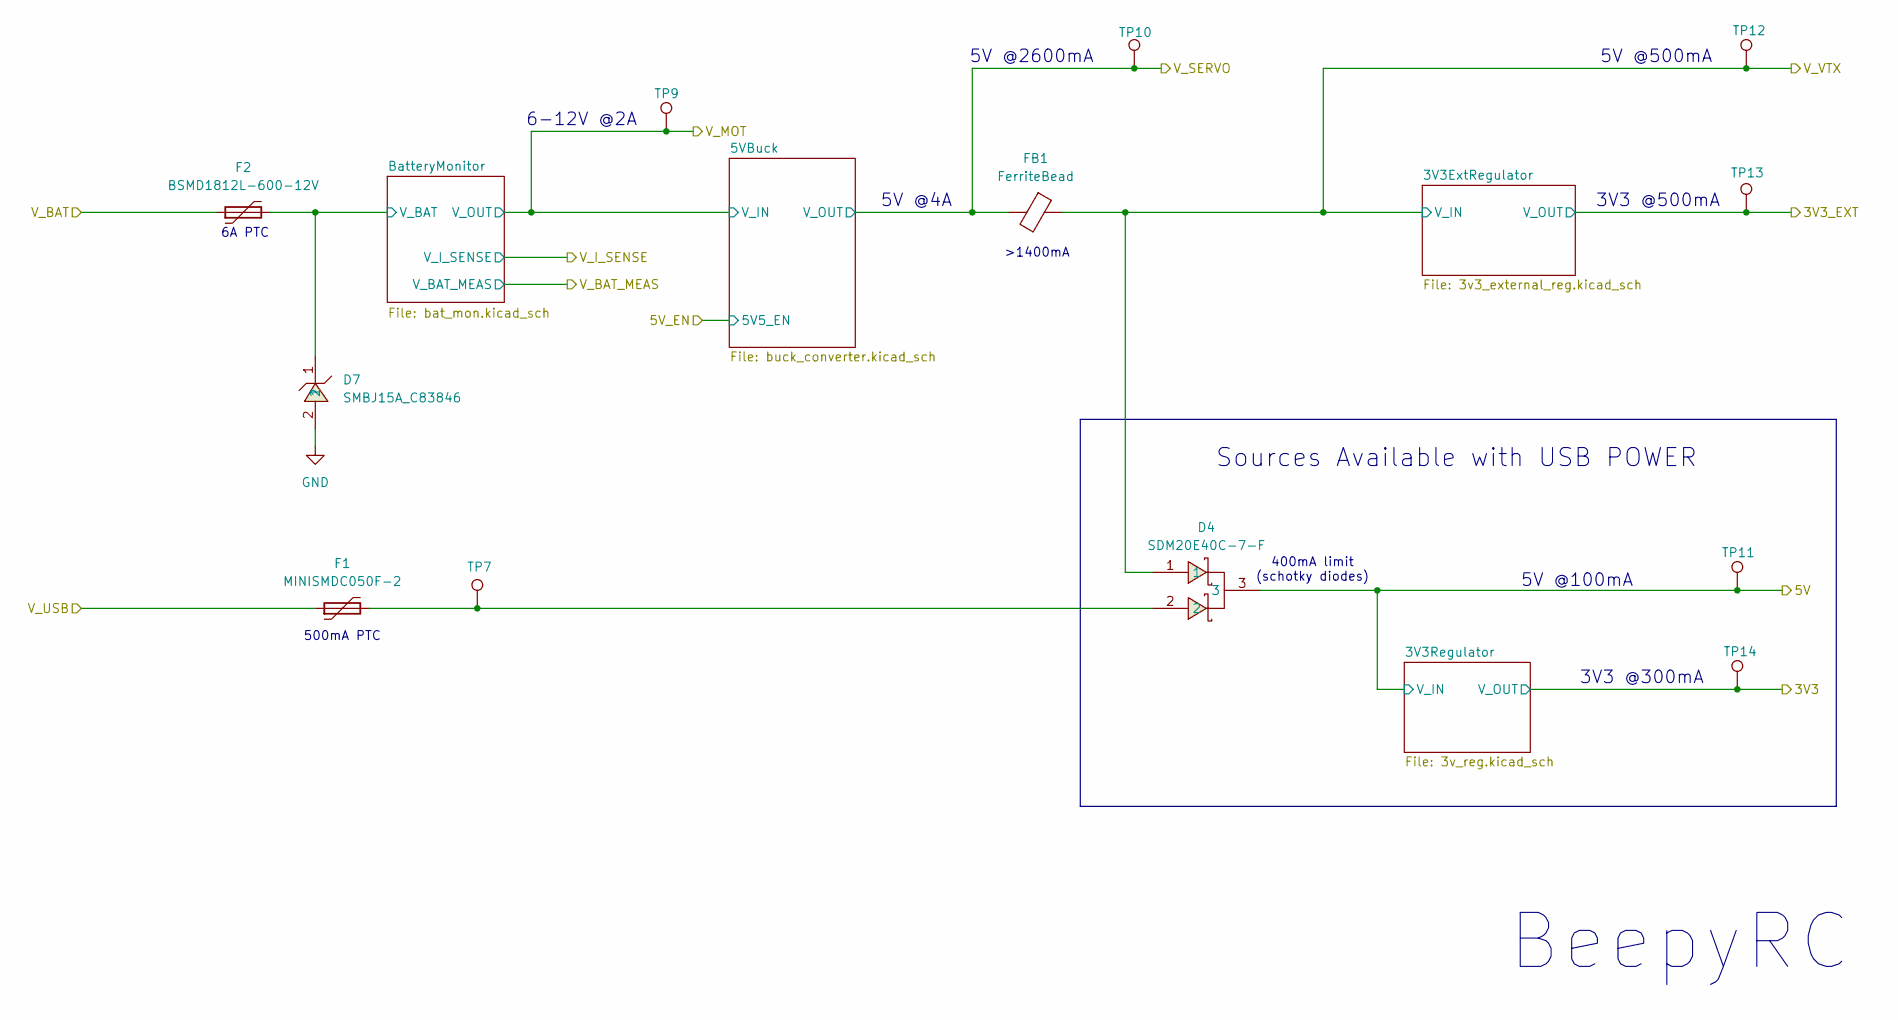
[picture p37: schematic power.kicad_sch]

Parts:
D4: SDM20E40C-7-F; SOT-23-3_L2.9-W1.6-P1.90-LS2.8-BR; LCSC Part C139437
D7: SMBJ15A_C83846; SMB_L4.6-W3.6-LS5.3-RD; LCSC Part C83846
F1: MINISMDC050F-2; Fuse_1812_4532Metric_Pad1.30x3.40mm_HandSolder
F2: BSMD1812L-600-12V; Fuse_1812_4532Metric_Pad1.30x3.40mm_HandSolder
FB1: FerriteBead; R_0603_1608Metric_Pad0.98x0.95mm_HandSolder
TP7, TP9, TP10, TP11, TP12, TP13, TP14: TestPoint; TestPoint_Pad_D1.0mm

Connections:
+5V: D4.3, TP11.1; also elsewhere on the board
/Power/BatteryMonitor/V_BAT: D7.1, F2.2; also elsewhere on the board
GND: D7.2; also elsewhere on the board
unnamed: D4.2, F1.2, TP7.1
V_3V3_EXT: TP13.1; also elsewhere on the board
V_BAT: F2.1; also elsewhere on the board
V_MCU: TP14.1; also elsewhere on the board
V_MOT: TP9.1; also elsewhere on the board
V_SERVO: FB1.2, TP10.1; also elsewhere on the board
V_USB: F1.1; also elsewhere on the board
V_VTX: D4.1, FB1.1, TP12.1; also elsewhere on the board

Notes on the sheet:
400mA limit (schotky diodes)
6A PTC
5V @2600mA
3V3 @500mA
Sources Available with USB POWER
5V @100mA
3V3 @300mA
500mA PTC
5V @4A
6-12V @2A
>1400mA
BeepyRC
5V @500mA

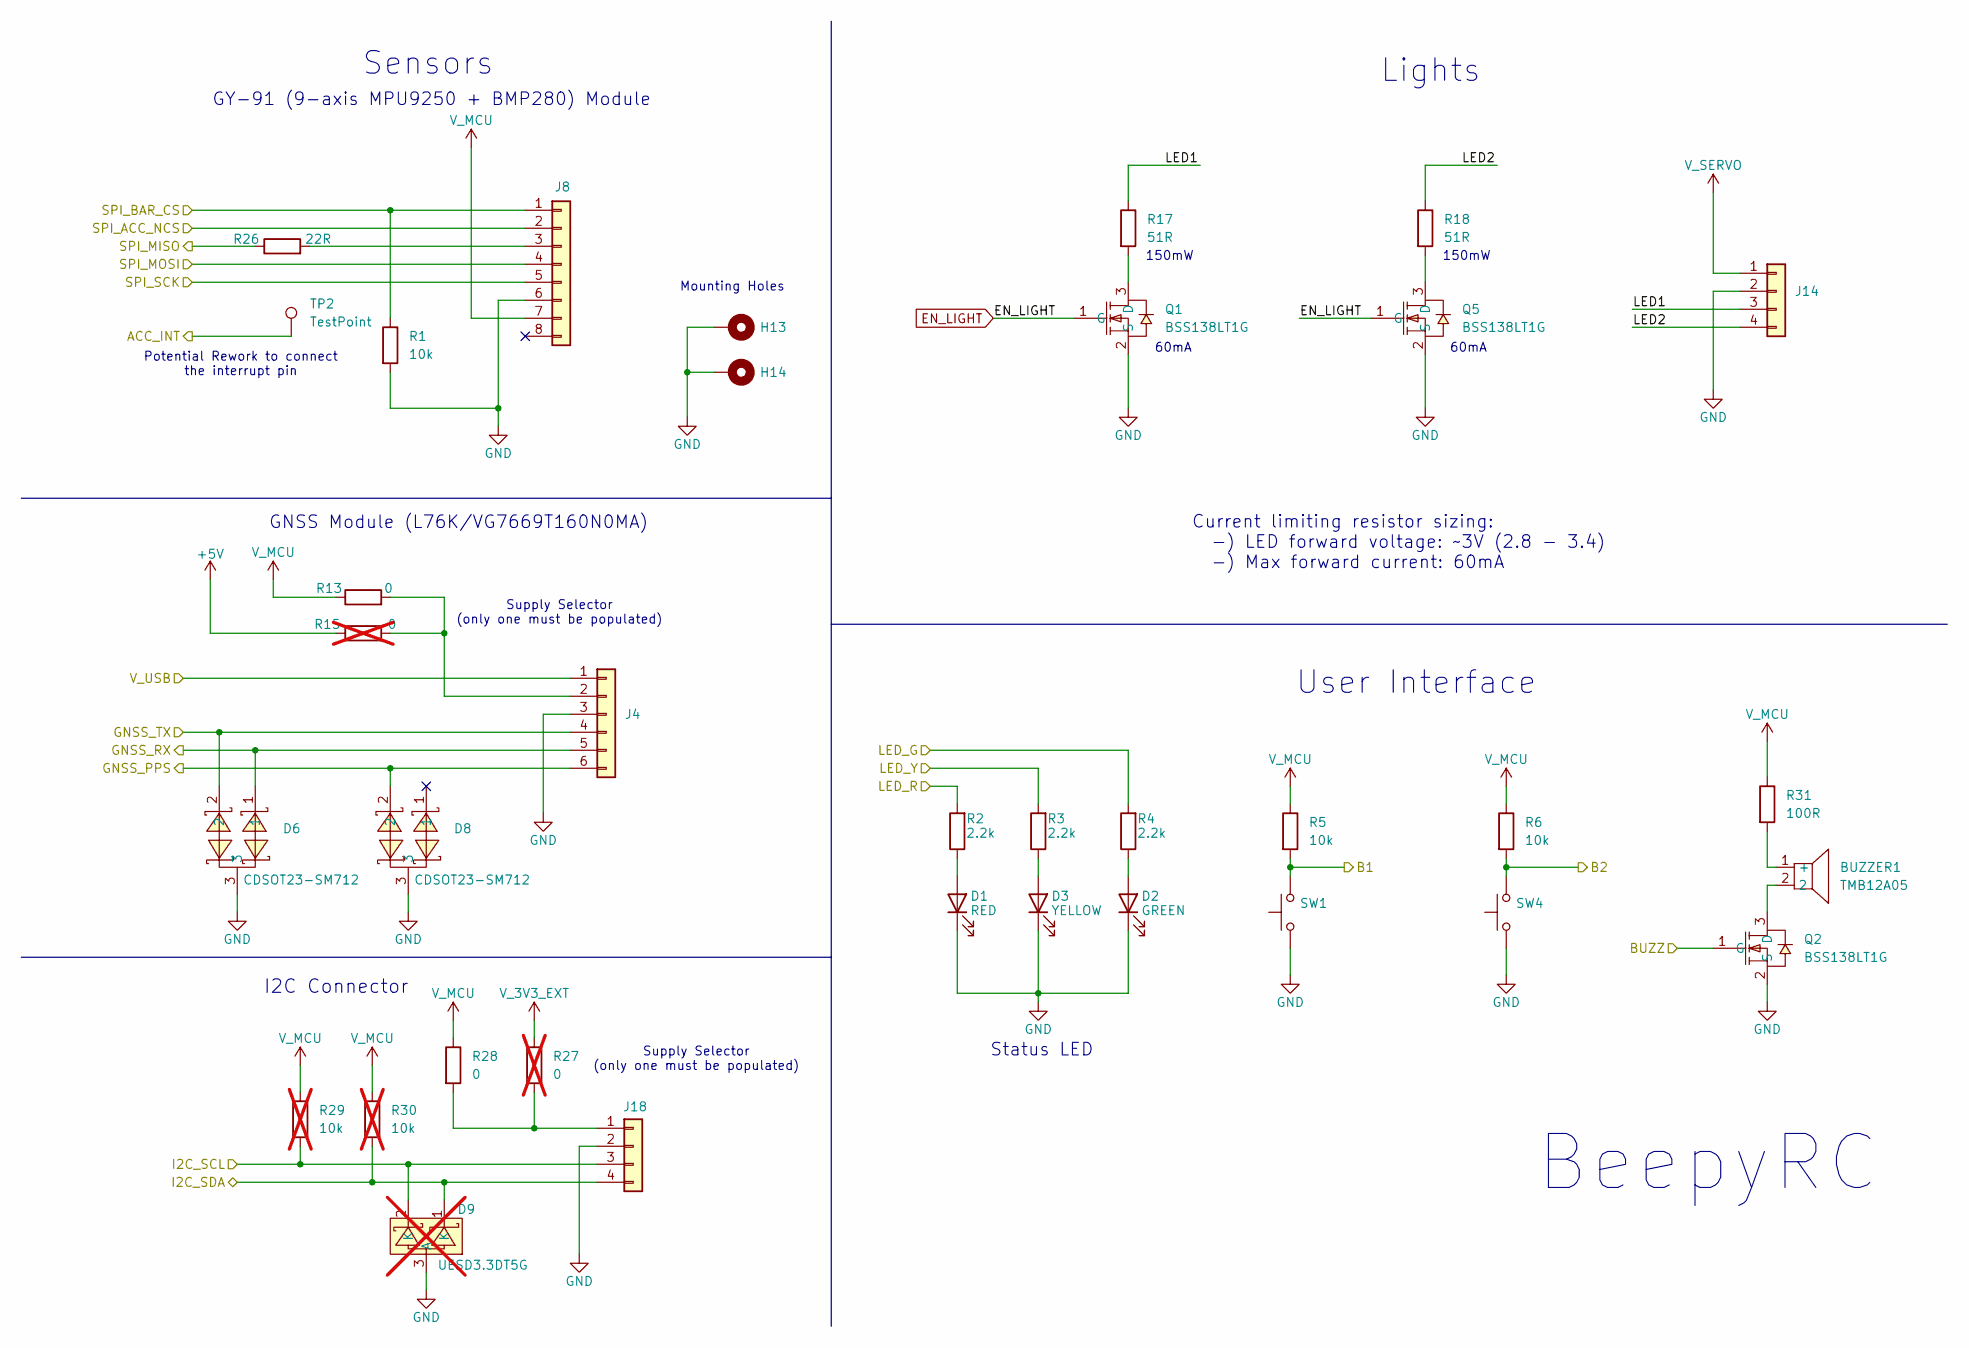
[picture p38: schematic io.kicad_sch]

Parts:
BUZZER1: TMB12A05; BUZ-TH_BD12.0-P7.60-D0.6-FD; LCSC Part C96093
D1: RED; LED_0603_1608Metric_Pad1.05x0.95mm_HandSolder
D2: GREEN; LED_0603_1608Metric_Pad1.05x0.95mm_HandSolder
D3: YELLOW; LED_0603_1608Metric_Pad1.05x0.95mm_HandSolder
D6, D8: CDSOT23-SM712; SOT-23_L2.9-W1.3-P1.90-LS2.4-BR; LCSC Part C404012
D9: UESD3.3DT5G; SOT-723_L1.2-W0.8-P0.40-LS1.2-BR; LCSC Part C233435; not fitted
H13, H14: MT; MountingHole_4.3mm_M4_DIN965_Pad_TopBottom
J4: Conn_01x06; PinHeader_1x06_P2.54mm_Vertical
J8: Conn_01x08; gy91
J14, J18: Conn_01x04; PinHeader_1x04_P2.54mm_Vertical
Q1, Q2, Q5: BSS138LT1G; SOT-23-3_L2.9-W1.6-P1.90-LS2.8-BR; LCSC Part C82045
R1, R5, R6: 10k; R_0603_1608Metric_Pad0.98x0.95mm_HandSolder
R2, R3, R4: 2.2k; R_0603_1608Metric_Pad0.98x0.95mm_HandSolder
R13, R28: 0; R_0603_1608Metric_Pad0.98x0.95mm_HandSolder
R15, R27: 0; R_0603_1608Metric_Pad0.98x0.95mm_HandSolder; not fitted
R17, R18: 51R; R_0603_1608Metric_Pad0.98x0.95mm_HandSolder
R26: 22R; R_0603_1608Metric_Pad0.98x0.95mm_HandSolder
R29, R30: 10k; R_0603_1608Metric_Pad0.98x0.95mm_HandSolder; not fitted
R31: 100R; R_0603_1608Metric_Pad0.98x0.95mm_HandSolder
SW1, SW4: SW_Push; SW-SMD_L3.9-W3.0-P4.45
TP2: TestPoint; TestPoint_Pad_D2.5mm

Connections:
+5V: R15.1; also elsewhere on the board
/ACC_INT: TP2.1; also elsewhere on the board
/ACC_NCS: J8.2; also elsewhere on the board
/B1: R5.2, SW1.2; also elsewhere on the board
/B2: R6.2, SW4.2; also elsewhere on the board
/BAR_CS: J8.1, R1.1; also elsewhere on the board
/BUZZ: Q2.1 (G); also elsewhere on the board
/GNSS_PPS: D8.2, J4.6; also elsewhere on the board
/GNSS_RX: D6.1, J4.5; also elsewhere on the board
/GNSS_TX: D6.2, J4.4; also elsewhere on the board
/I2C_SCL: D9.2 (K), J18.3, R29.2; also elsewhere on the board
/I2C_SDA: D9.1 (K), J18.4, R30.2; also elsewhere on the board
/IO/LED1: J14.3, R17.1
/IO/LED2: J14.4, R18.1
/LED_G: R4.2; also elsewhere on the board
/LED_R: R2.2; also elsewhere on the board
/LED_Y: R3.2; also elsewhere on the board
/SPI_MISO: R26.1; also elsewhere on the board
/SPI_MOSI: J8.4; also elsewhere on the board
/SPI_SCK: J8.5; also elsewhere on the board
EN_LIGHT: Q1.1 (G), Q5.1 (G)
GND: D1.1 (K), D2.1 (K), D3.1 (K), D6.3, D8.3, D9.3 (A), H13.1, H14.1, J4.3, J8.6, J14.2, J18.2, Q1.2 (S), Q2.2 (S), Q5.2 (S), R1.2, SW1.1, SW4.1; also elsewhere on the board
unnamed: BUZZER1.1 (+), R31.2
unnamed: D1.2 (A), R2.1
unnamed: D2.2 (A), R4.1
unnamed: D3.2 (A), R3.1
unnamed: J4.2, R13.2, R15.2
unnamed: J8.3, R26.2
unnamed: J18.1, R27.2, R28.2
unnamed: Q1.3 (D), R17.2
unnamed: BUZZER1.2, Q2.3 (D)
unnamed: Q5.3 (D), R18.2
V_3V3_EXT: R27.1; also elsewhere on the board
V_MCU: J8.7, R5.1, R6.1, R13.1, R28.1, R29.1, R30.1, R31.1; also elsewhere on the board
V_SERVO: J14.1; also elsewhere on the board
V_USB: J4.1; also elsewhere on the board

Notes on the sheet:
150mW
60mA
BeepyRC
Lights
GNSS Module (L76K/VG7669T160N0MA)
User Interface
Supply Selector (only one must be populated)
Potential Rework to connect the interrupt pin
Status LED
GY-91 (9-axis MPU9250 + BMP280) Module
I2C Connector
Current limiting resistor sizing: -) LED forward voltage: ~3V (2.8 - 3.4) -) Max forward current: 60mA
Sensors
Mounting Holes

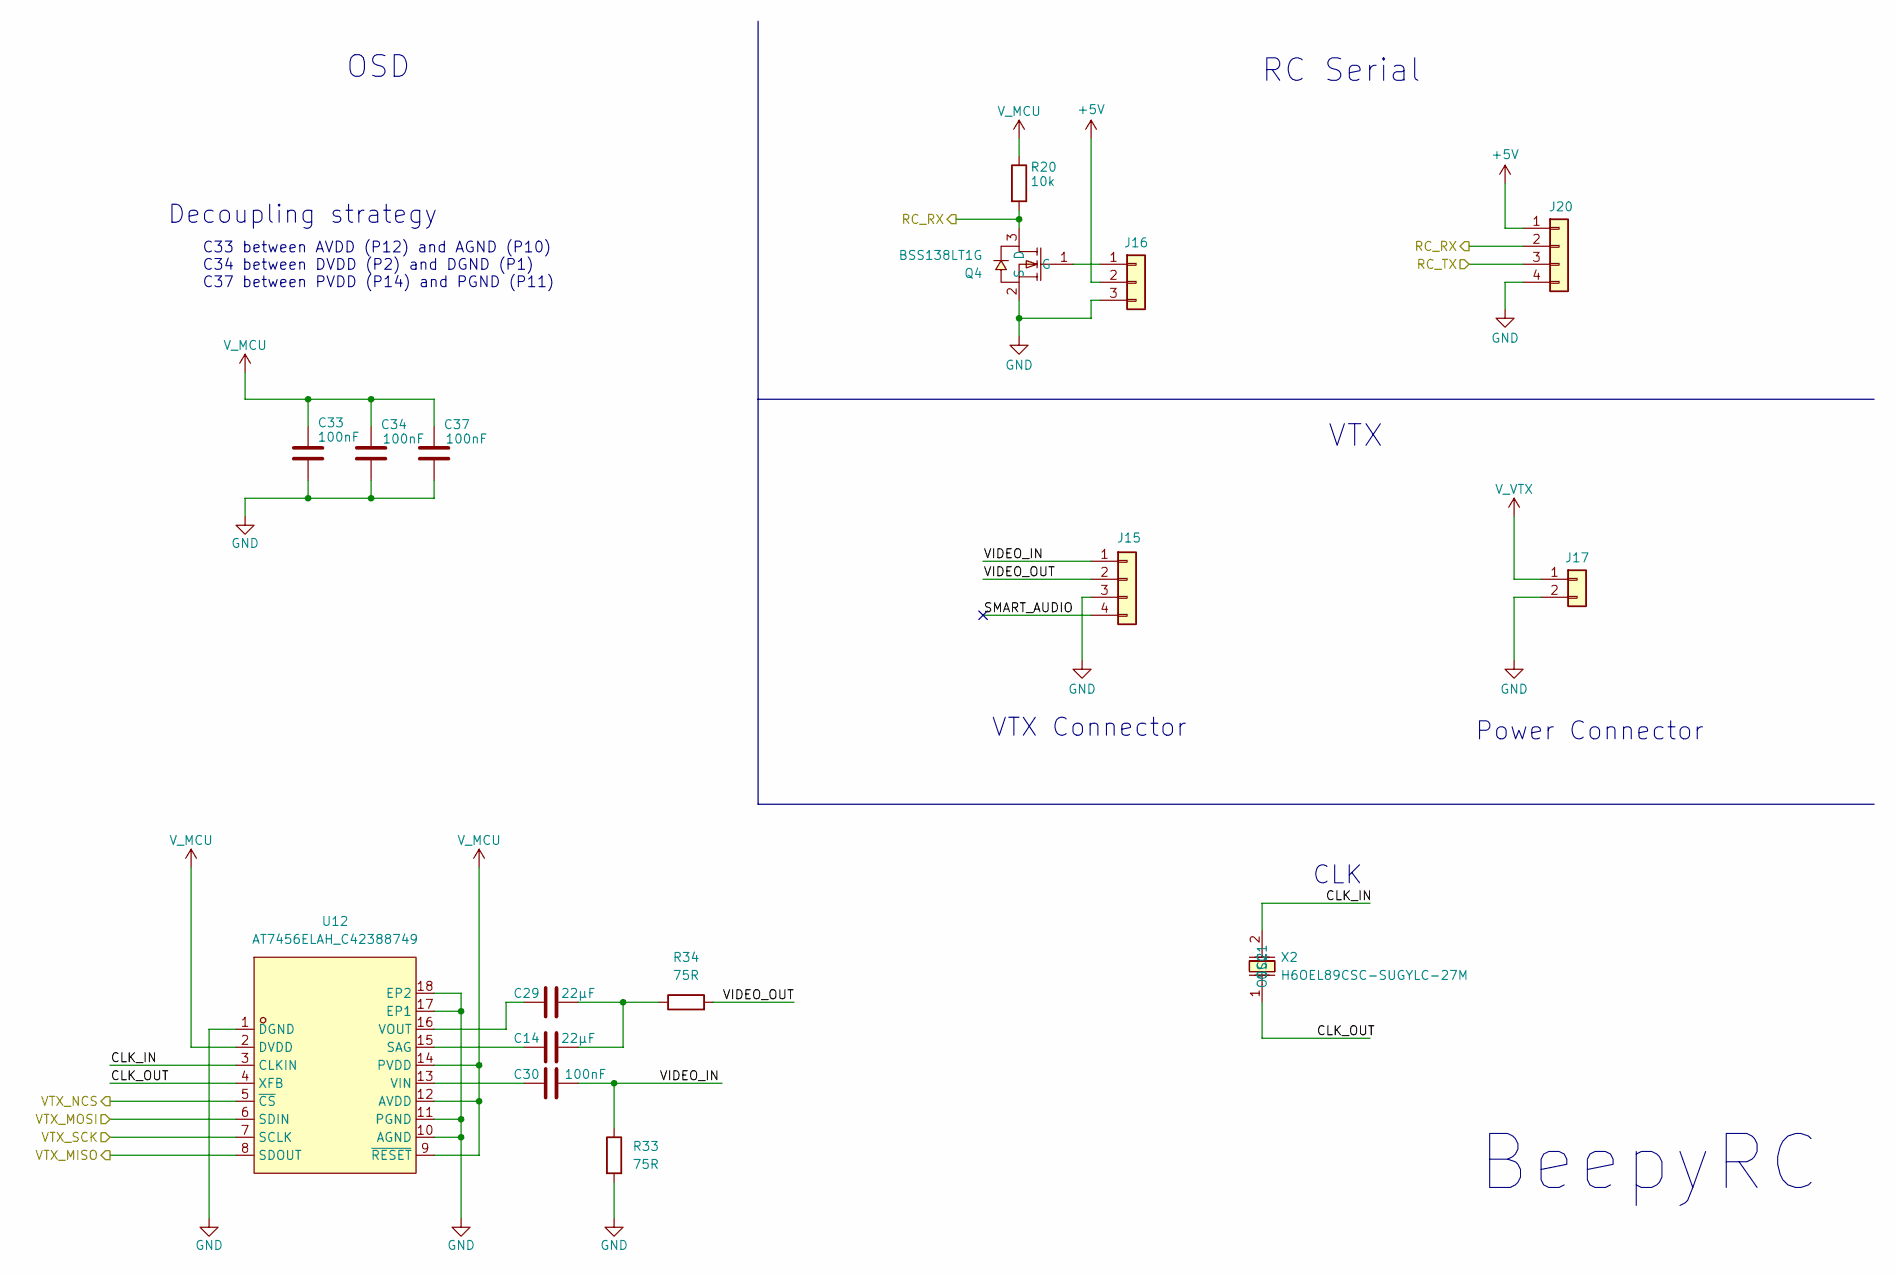
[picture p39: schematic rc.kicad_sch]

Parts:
C14, C29: 22μF; C_0603_1608Metric_Pad1.08x0.95mm_HandSolder
C30, C33, C34, C37: 100nF; C_0603_1608Metric_Pad1.08x0.95mm_HandSolder
J15, J20: Conn_01x04; PinHeader_1x04_P2.54mm_Vertical
J16: Conn_01x03; rc
J17: Conn_01x02; PinHeader_1x02_P2.54mm_Vertical
Q4: BSS138LT1G; SOT-23-3_L2.9-W1.6-P1.90-LS2.8-BR; LCSC Part C82045
R20: 10k; R_0603_1608Metric_Pad0.98x0.95mm_HandSolder
R33, R34: 75R; R_0603_1608Metric_Pad0.98x0.95mm_HandSolder
U12: AT7456ELAH_C42388749; LGA-16_L6.8-W4.0-P0.65-TL-2EP; LCSC Part C42388749
X2: H6OEL89CSC-SUGYLC-27M; HC-49S_L11.4-W4.8-LS12.7; LCSC Part C19078186

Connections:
+5V: J16.2, J20.1; also elsewhere on the board
/RC/CLK_IN: U12.3 (CLKIN), X2.2 (OSC2)
/RC/CLK_OUT: U12.4 (XFB), X2.1 (OSC1)
/RC/SMART_AUDIO: J15.4
/RC/VIDEO_IN: C30.2, J15.1, R33.1
/RC/VIDEO_OUT: J15.2, R34.2
/RC_RX: J20.2, Q4.3 (D), R20.2; also elsewhere on the board
/RC_TX: J20.3; also elsewhere on the board
/SPI_MISO: U12.8 (SDOUT); also elsewhere on the board
/SPI_MOSI: U12.6 (SDIN); also elsewhere on the board
/SPI_SCK: U12.7 (SCLK); also elsewhere on the board
/VTX_CS: U12.5 (~CS); also elsewhere on the board
GND: C33.2, C34.2, C37.2, J15.3, J16.3, J17.2, J20.4, Q4.2 (S), R33.2, U12.1 (DGND), U12.10 (AGND), U12.11 (PGND), U12.17 (EP1), U12.18 (EP2); also elsewhere on the board
unnamed: C14.2, C29.2, R34.1
unnamed: J16.1, Q4.1 (G)
unnamed: C14.1, U12.15 (SAG)
unnamed: C30.1, U12.13 (VIN)
unnamed: C29.1, U12.16 (VOUT)
V_MCU: C33.1, C34.1, C37.1, R20.1, U12.2 (DVDD), U12.9 (~RESET), U12.12 (AVDD), U12.14 (PVDD); also elsewhere on the board
V_VTX: J17.1; also elsewhere on the board

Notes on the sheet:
BeepyRC
OSD
VTX
VTX Connector
C33 between AVDD (P12) and AGND (P10) C34 between DVDD (P2) and DGND (P1) C37 between PVDD (P14) and PGND (P11)
CLK
Decoupling strategy
Power Connector
RC Serial

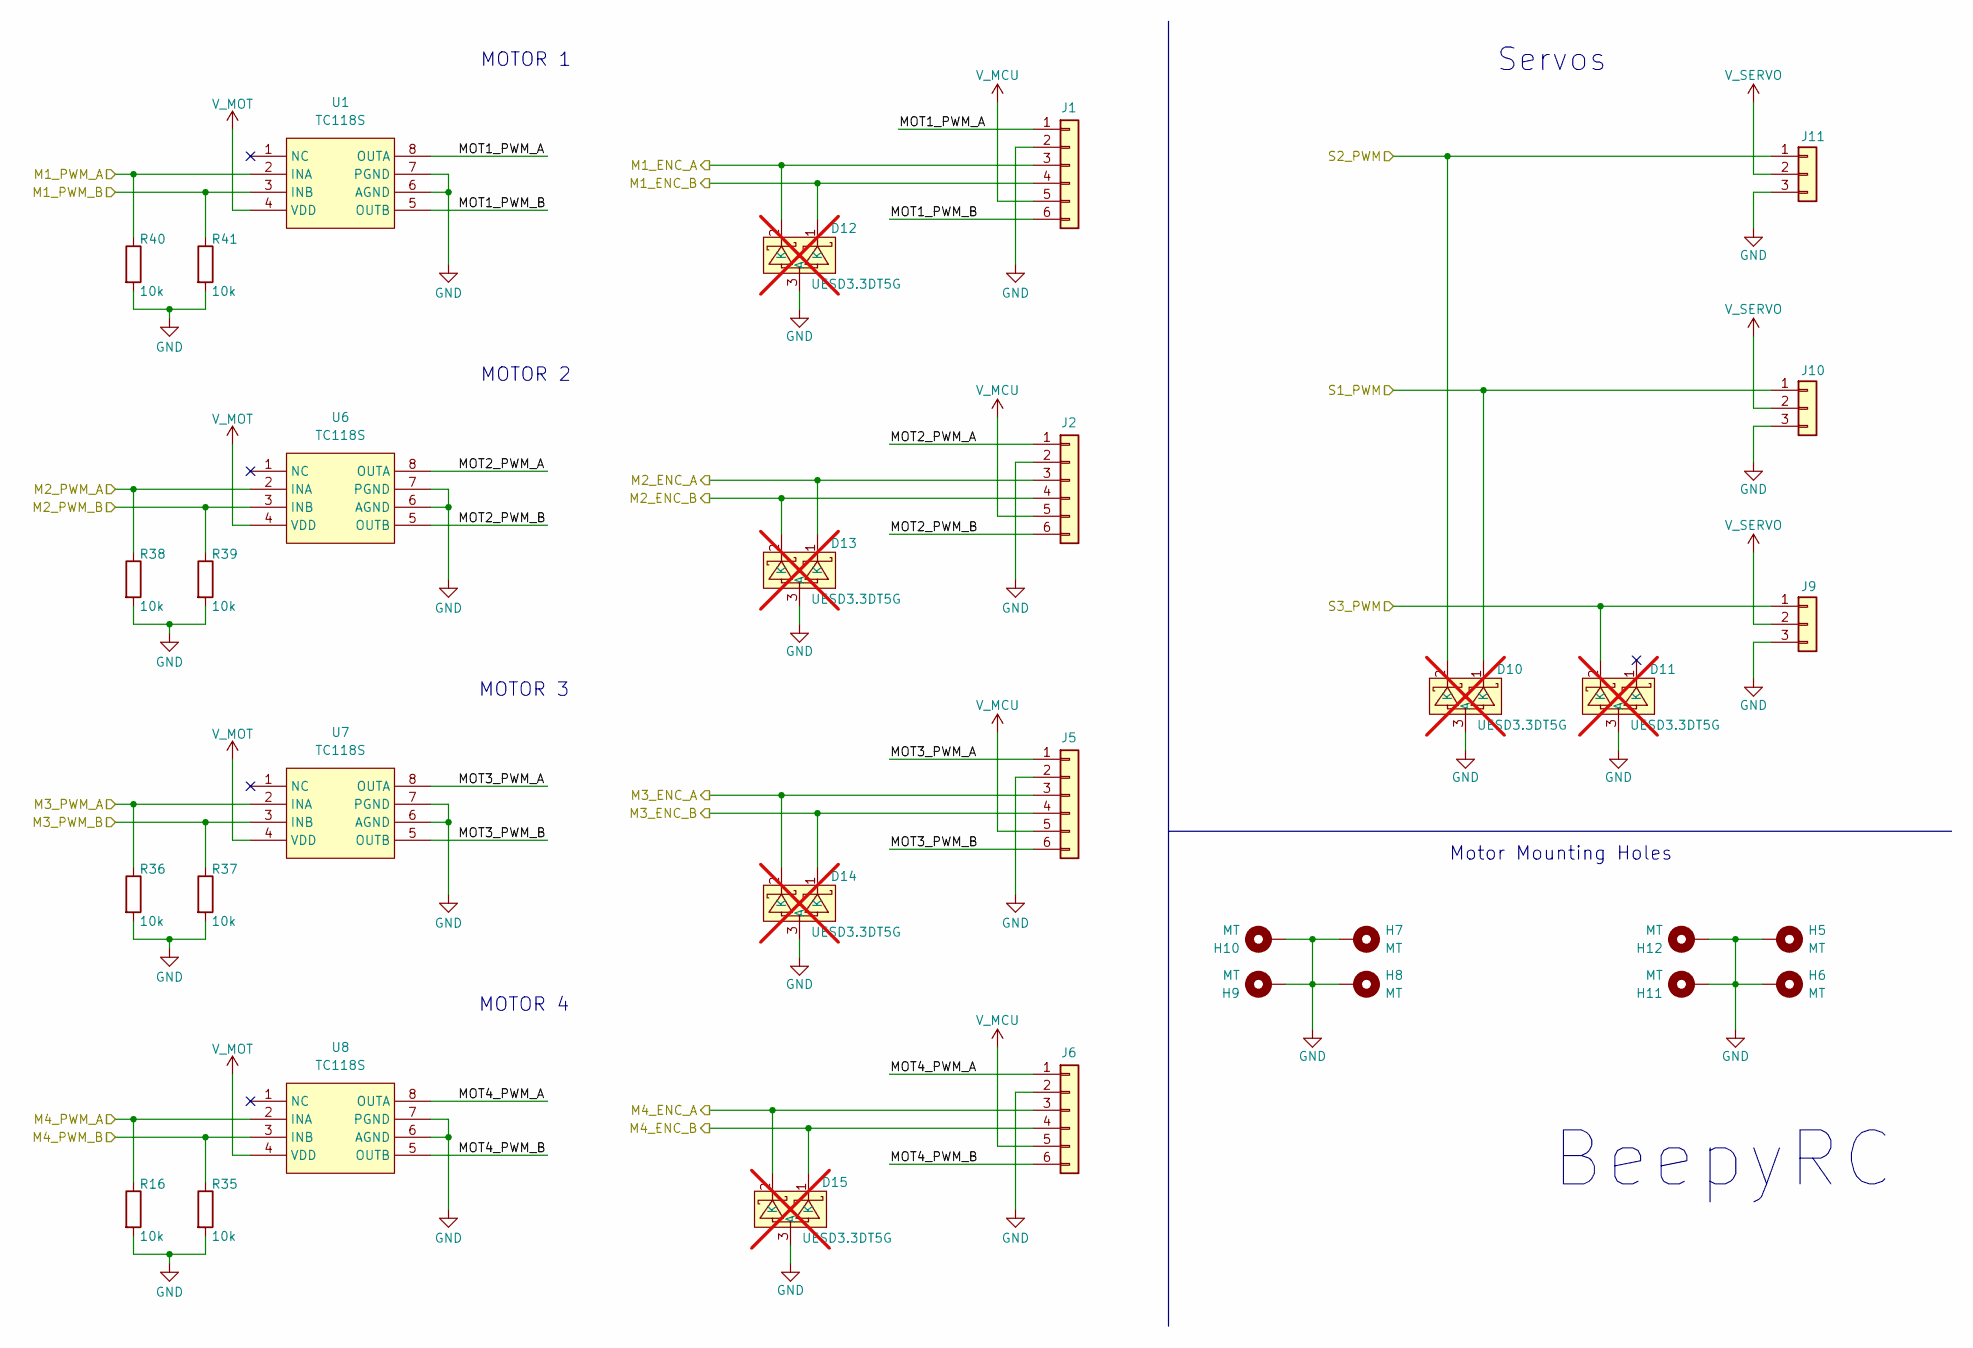
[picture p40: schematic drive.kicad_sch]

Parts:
D10, D11, D12, D13, D14, D15: UESD3.3DT5G; SOT-723_L1.2-W0.8-P0.40-LS1.2-BR; LCSC Part C233435; not fitted
H5, H6, H7, H8, H9, H10, H11, H12: MT; MountingHole_2.2mm_M2_DIN965_Pad_TopBottom
J1, J2, J5, J6: Conn_01x06; PinHeader_1x06_P2.54mm_Vertical
J9, J10, J11: Conn_01x03; PinHeader_1x03_P2.54mm_Vertical
R16, R35, R36, R37, R38, R39, R40, R41: 10k; R_0603_1608Metric_Pad0.98x0.95mm_HandSolder
U1, U6, U7, U8: TC118S; SOP-8_L4.9-W3.9-P1.27-LS6.0-BL; LCSC Part C88308

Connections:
/Drive/MOT1_PWM_A: J1.1, U1.8 (OUTA)
/Drive/MOT1_PWM_B: J1.6, U1.5 (OUTB)
/Drive/MOT2_PWM_A: J2.1, U6.8 (OUTA)
/Drive/MOT2_PWM_B: J2.6, U6.5 (OUTB)
/Drive/MOT3_PWM_A: J5.1, U7.8 (OUTA)
/Drive/MOT3_PWM_B: J5.6, U7.5 (OUTB)
/Drive/MOT4_PWM_A: J6.1, U8.8 (OUTA)
/Drive/MOT4_PWM_B: J6.6, U8.5 (OUTB)
/M1_ENC_A: D12.2 (K), J1.3; also elsewhere on the board
/M1_ENC_B: D12.1 (K), J1.4; also elsewhere on the board
/M1_PWM_A: R40.1, U1.2 (INA); also elsewhere on the board
/M1_PWM_B: R41.1, U1.3 (INB); also elsewhere on the board
/M2_ENC_A: D13.1 (K), J2.3; also elsewhere on the board
/M2_ENC_B: D13.2 (K), J2.4; also elsewhere on the board
/M2_PWM_A: R38.1, U6.2 (INA); also elsewhere on the board
/M2_PWM_B: R39.1, U6.3 (INB); also elsewhere on the board
/M3_ENC_A: D14.2 (K), J5.3; also elsewhere on the board
/M3_ENC_B: D14.1 (K), J5.4; also elsewhere on the board
/M3_PWM_A: R36.1, U7.2 (INA); also elsewhere on the board
/M3_PWM_B: R37.1, U7.3 (INB); also elsewhere on the board
/M4_ENC_A: D15.2 (K), J6.3; also elsewhere on the board
/M4_ENC_B: D15.1 (K), J6.4; also elsewhere on the board
/M4_PWM_A: R16.1, U8.2 (INA); also elsewhere on the board
/M4_PWM_B: R35.1, U8.3 (INB); also elsewhere on the board
/SERVO1_PWM: D10.1 (K), J10.1; also elsewhere on the board
/SERVO2_PWM: D10.2 (K), J11.1; also elsewhere on the board
/SERVO3_PWM: D11.2 (K), J9.1; also elsewhere on the board
GND: D10.3 (A), D11.3 (A), D12.3 (A), D13.3 (A), D14.3 (A), D15.3 (A), H5.1, H6.1, H7.1, H8.1, H9.1, H10.1, H11.1, H12.1, J1.2, J2.2, J5.2, J6.2, J9.3, J10.3, J11.3, R16.2, R35.2, R36.2, R37.2, R38.2, R39.2, R40.2, R41.2, U1.6 (AGND), U1.7 (PGND), U6.6 (AGND), U6.7 (PGND), U7.6 (AGND), U7.7 (PGND), U8.6 (AGND), U8.7 (PGND); also elsewhere on the board
V_MCU: J1.5, J2.5, J5.5, J6.5; also elsewhere on the board
V_MOT: U1.4 (VDD), U6.4 (VDD), U7.4 (VDD), U8.4 (VDD); also elsewhere on the board
V_SERVO: J9.2, J10.2, J11.2; also elsewhere on the board

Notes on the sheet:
MOTOR 3
Motor Mounting Holes
MOTOR 4
MOTOR 2
BeepyRC
Servos
MOTOR 1

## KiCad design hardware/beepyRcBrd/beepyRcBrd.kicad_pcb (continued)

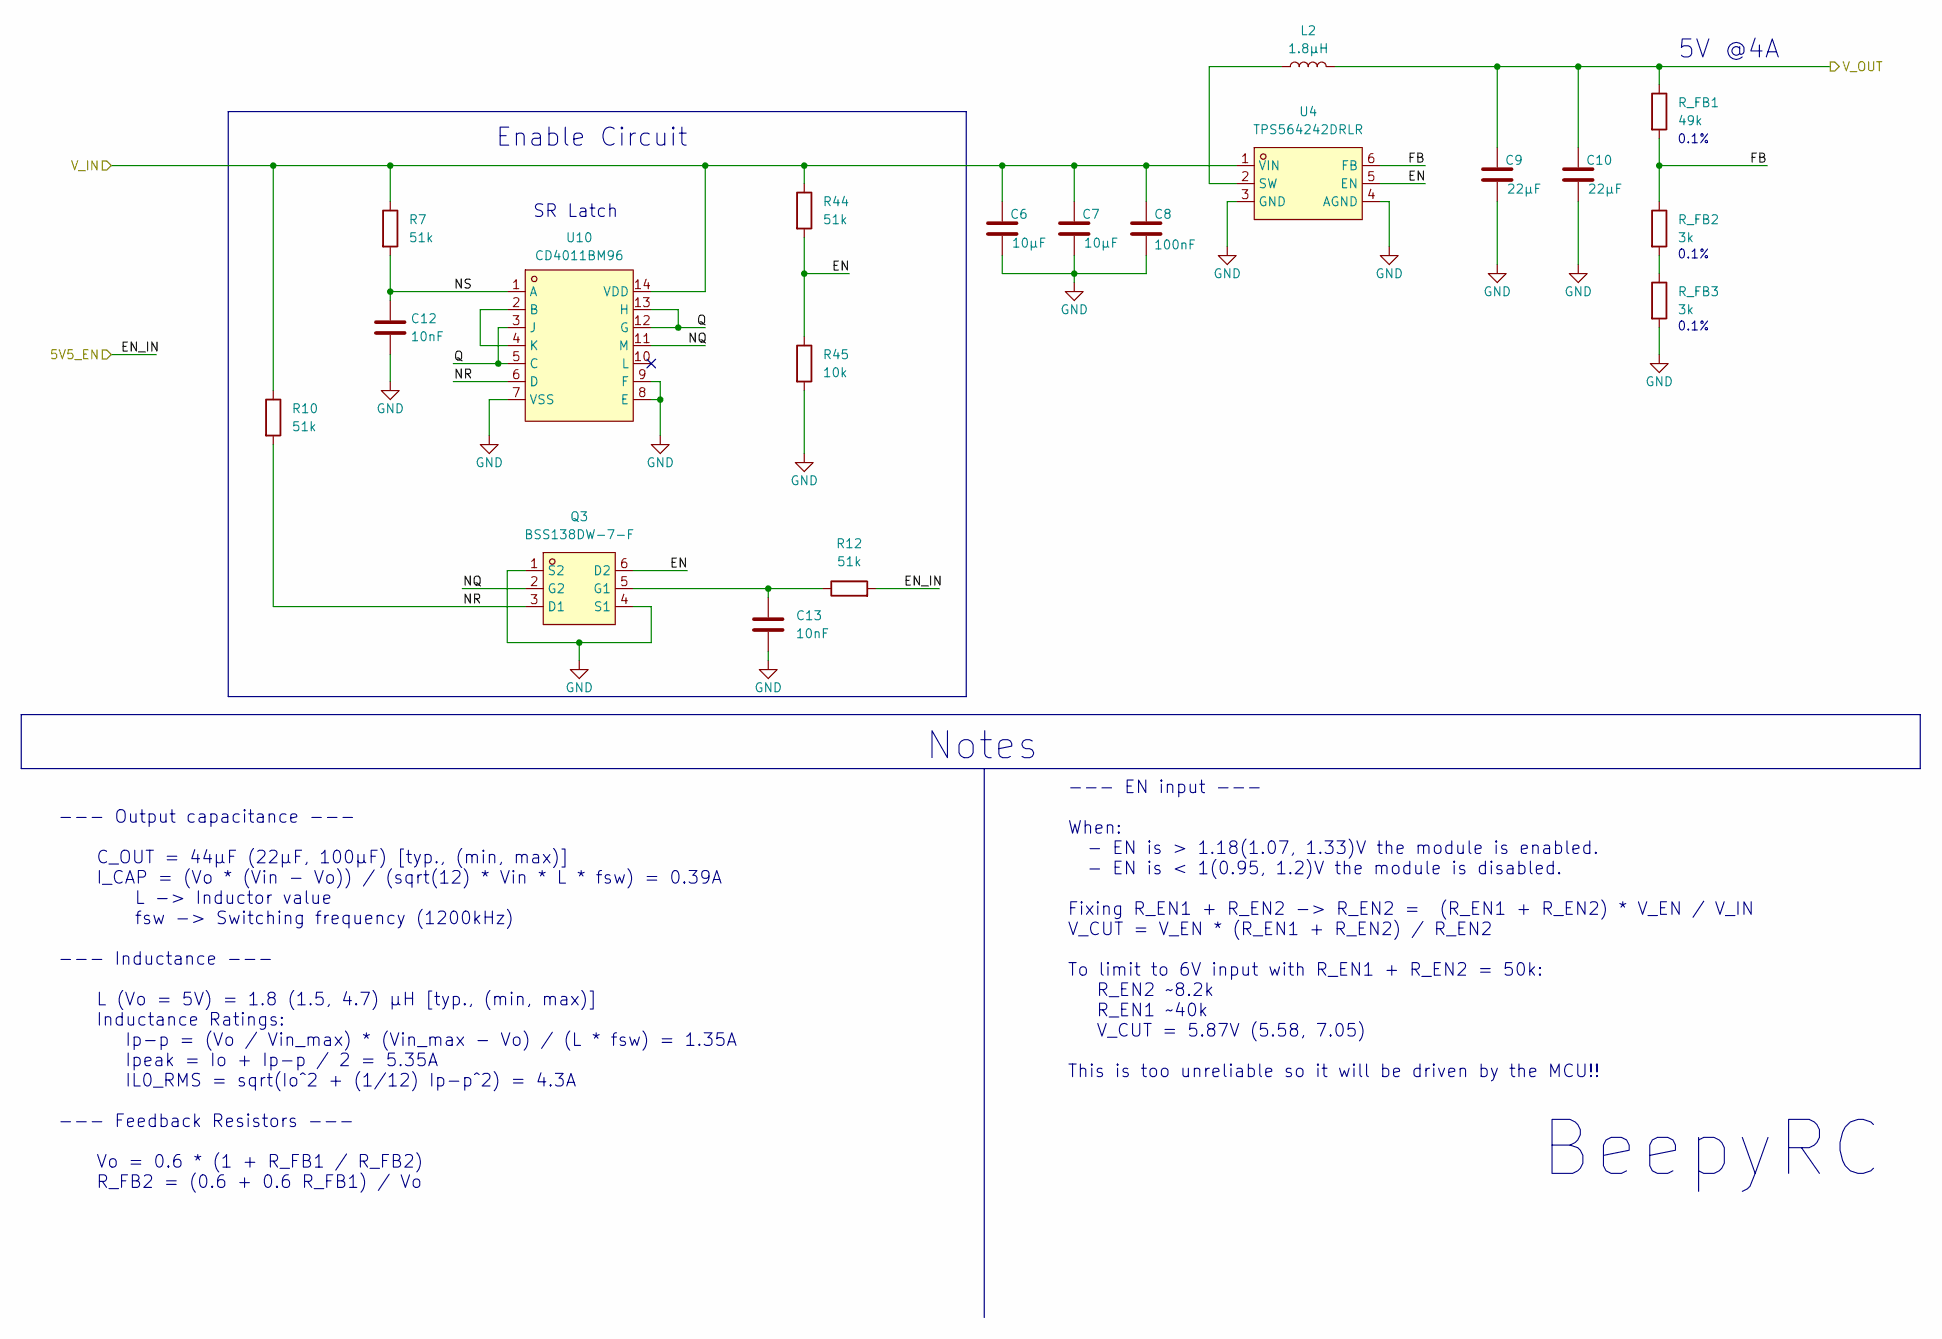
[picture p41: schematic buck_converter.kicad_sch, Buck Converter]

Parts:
C6, C7: 10μF; C_0603_1608Metric_Pad1.08x0.95mm_HandSolder
C8: 100nF; C_0603_1608Metric_Pad1.08x0.95mm_HandSolder
C9, C10: 22μF; C_0603_1608Metric_Pad1.08x0.95mm_HandSolder
C12, C13: 10nF; C_0603_1608Metric_Pad1.08x0.95mm_HandSolder
L2: 1.8μH; IND-SMD_L7.0-W6.6_MCW-0650-220
Q3: BSS138DW-7-F; SC-70-6_L2.2-W1.3-P0.65-LS2.1-TL; LCSC Part C154900
R7, R10, R12, R44: 51k; R_0603_1608Metric_Pad0.98x0.95mm_HandSolder
R45: 10k; R_0603_1608Metric_Pad0.98x0.95mm_HandSolder
R_FB1: 49k; R_0603_1608Metric_Pad0.98x0.95mm_HandSolder
R_FB2, R_FB3: 3k; R_0603_1608Metric_Pad0.98x0.95mm_HandSolder
U4: TPS564242DRLR; SOT-5X3-6_W1.6-L1.2-P0.50-LS1.6-BL; LCSC Part C5219267
U10: CD4011BM96; SOIC-14_L8.7-W3.9-P1.27-LS6.0-BL; LCSC Part C48466

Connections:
/EN_BAT: R12.2; also elsewhere on the board
/Power/5VBuck/EN: Q3.6 (D2), R44.2, R45.1, U4.5 (EN)
/Power/5VBuck/FB: R_FB1.2, R_FB2.1, U4.6 (FB)
/Power/5VBuck/NQ: Q3.2 (G2), U10.11 (M)
/Power/5VBuck/NR: Q3.3 (D1), R10.2, U10.6 (D)
/Power/5VBuck/NS: C12.1, R7.2, U10.1 (A)
/Power/5VBuck/Q: U10.3 (J), U10.5 (C), U10.12 (G), U10.13 (H)
GND: C6.2, C7.2, C8.2, C9.2, C10.2, C12.2, C13.2, Q3.1 (S2), Q3.4 (S1), R45.2, R_FB3.2, U4.3 (GND), U4.4 (AGND), U10.7 (VSS), U10.8 (E), U10.9 (F); also elsewhere on the board
unnamed: C13.1, Q3.5 (G1), R12.1
unnamed: R_FB2.2, R_FB3.1
unnamed: L2.1, U4.2 (SW)
unnamed: U10.2 (B), U10.4 (K)
V_MOT: C6.1, C7.1, C8.1, R7.1, R10.1, R44.1, U4.1 (VIN), U10.14 (VDD); also elsewhere on the board
V_SERVO: C9.1, C10.1, L2.2, R_FB1.1; also elsewhere on the board

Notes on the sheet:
0.1%
5V @4A
SR Latch
Enable Circuit
--- Output capacitance --- C_OUT = 44μF (22μF, 100μF) [typ., (min, max)] I_CAP = (Vo * (Vin - Vo)) / (sqrt(12) * Vin * L * fsw) = 0.39A L -> Inductor value fsw -> Switching frequency (1200kHz) --- Inductance --- L (Vo = 5V) = 1.8 (1.5, 4.7) μH [typ., (min, max)] Inductance Ratings: Ip-p = (Vo / Vin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
BeepyRC
--- EN input --- When: - EN is > 1.18(1.07, 1.33)V the module is enabled. - EN is < 1(0.95, 1.2)V the module is disabled. Fixing R_EN1 + R_EN2 -> R_EN2 = (R_EN1 + R_EN2) * V_EN / V_IN V_CUT = V_EN * (R_EN1 + R_EN2) / R_EN2 To limit to 6V input with R_EN1 + R_EN2 = 50k: R_EN2 ~8.2k R_EN1 ~40k V_CUT 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
Notes

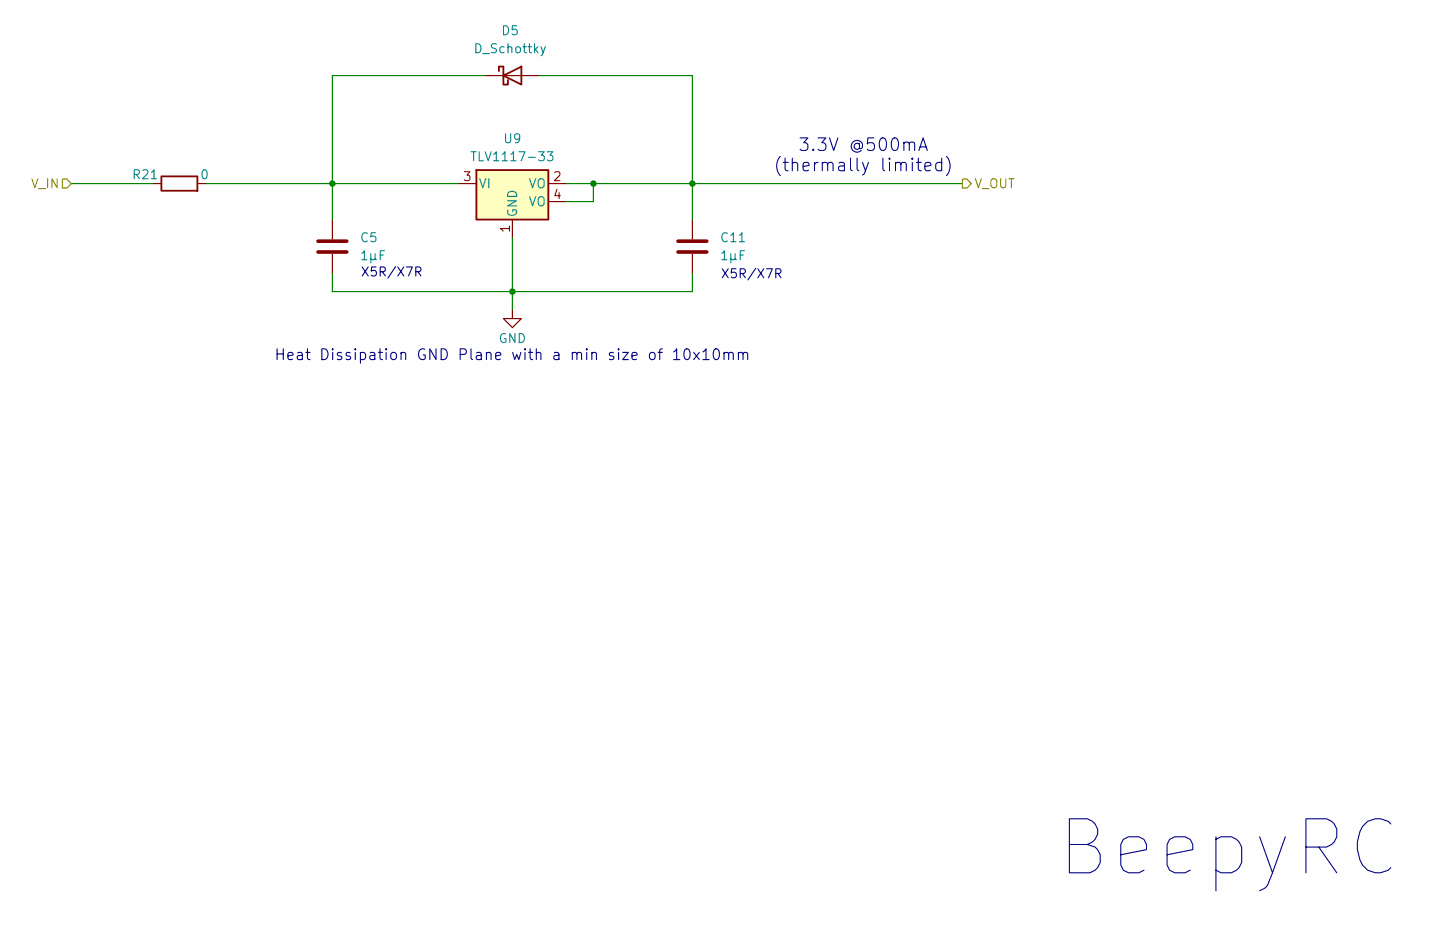
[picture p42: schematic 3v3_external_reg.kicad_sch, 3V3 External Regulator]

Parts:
C5, C11: 1μF; C_0603_1608Metric_Pad1.08x0.95mm_HandSolder
D5: D_Schottky; D_SOD-323
R21: 0; R_0603_1608Metric_Pad0.98x0.95mm_HandSolder
U9: TLV1117-33; SOT-223_L6.5-W3.5-P2.30-LS7.0-BR

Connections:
GND: C5.2, C11.2, U9.1 (GND); also elsewhere on the board
unnamed: C5.1, D5.1 (K), R21.2, U9.3 (VI)
V_3V3_EXT: C11.1, D5.2 (A), U9.2 (VO), U9.4 (VO); also elsewhere on the board
V_VTX: R21.1; also elsewhere on the board

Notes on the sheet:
3.3V @500mA (thermally limited)
X5R/X7R
BeepyRC
Heat Dissipation GND Plane with a min size of 10x10mm

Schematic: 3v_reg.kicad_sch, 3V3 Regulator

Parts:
C3, C4: 1μF; C_0603_1608Metric_Pad1.08x0.95mm_HandSolder
U5: MC33275ST-3.3T3G; SOT-223_L6.5-W3.5-P2.30-LS7.0-BR; LCSC Part C153747

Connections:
+5V: C3.1, U5.1 (VIN); also elsewhere on the board
GND: C3.2, C4.2, U5.2 (GND), U5.4 (TAB); also elsewhere on the board
V_MCU: C4.1, U5.3 (VOUT); also elsewhere on the board

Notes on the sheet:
BeepyRC
Heat Dissipation GND Plane with a min size of 10x10mm
3.3V @300mA
X5R/X7R

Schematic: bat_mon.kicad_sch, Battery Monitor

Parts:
C1: 5.1nF; C_0603_1608Metric_Pad1.08x0.95mm_HandSolder
C2: 18nF; C_0603_1608Metric_Pad1.08x0.95mm_HandSolder
R11: 30k; R_0603_1608Metric_Pad0.98x0.95mm_HandSolder
R42: 40k; R_0603_1608Metric_Pad0.98x0.95mm_HandSolder
R43: 10k; R_0603_1608Metric_Pad0.98x0.95mm_HandSolder
Rs1: 17m; R_1206_3216Metric_Pad1.30x1.75mm_HandSolder
U3: INA139; SOT-23-5

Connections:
/Power/BatteryMonitor/V_BAT: R42.1, Rs1.1, U3.3 (+), U3.5 (V+); also elsewhere on the board
/V_BAT_MEAS: C2.1, R42.2, R43.1; also elsewhere on the board
/V_I_SENSE: C1.1, R11.1, U3.1; also elsewhere on the board
GND: C1.2, C2.2, R11.2, R43.2, U3.2 (GND); also elsewhere on the board
V_MOT: Rs1.2, U3.4 (-); also elsewhere on the board

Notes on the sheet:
V_BAT_MEAS = 0.24 * V_BAT
--- INA139 --- Output Voltage: Vo = Is * 1mA/V * R_L Vs full scale = 100mV (could also be 50mV to 500mV) R_L -> Set to generate ~3V at 6A (<50kOhm, ADC external resistance limit) C_L -> Low pass filter with a cut-off frequency at ~1kHz
--- Battery Voltage --- 2S battery range 6 - 8.4V, with 7.4 nominal Maximum ranges 6 - 12V --> Limited by the N20 motors R_SENSE is set to: 1. Be <50kOhm (ADC external resistance limit), 2. V_BAT_MEAS is ~3V @ 12V 3. Low-pass filter with Fc ~1kHz
Is = 0.51A/V * V_I_SENSE (fc = 1.04kHz)
--- Shunt Resistor --- Vs = 100mV with max current max(Is) = 6A > (4 * 0.35A for the motors + 4A for the 5.5V rail) Rs = Vs / max(Is) = ~17mOhm Power Rating: 0.6W
0.1%
BeepyRC

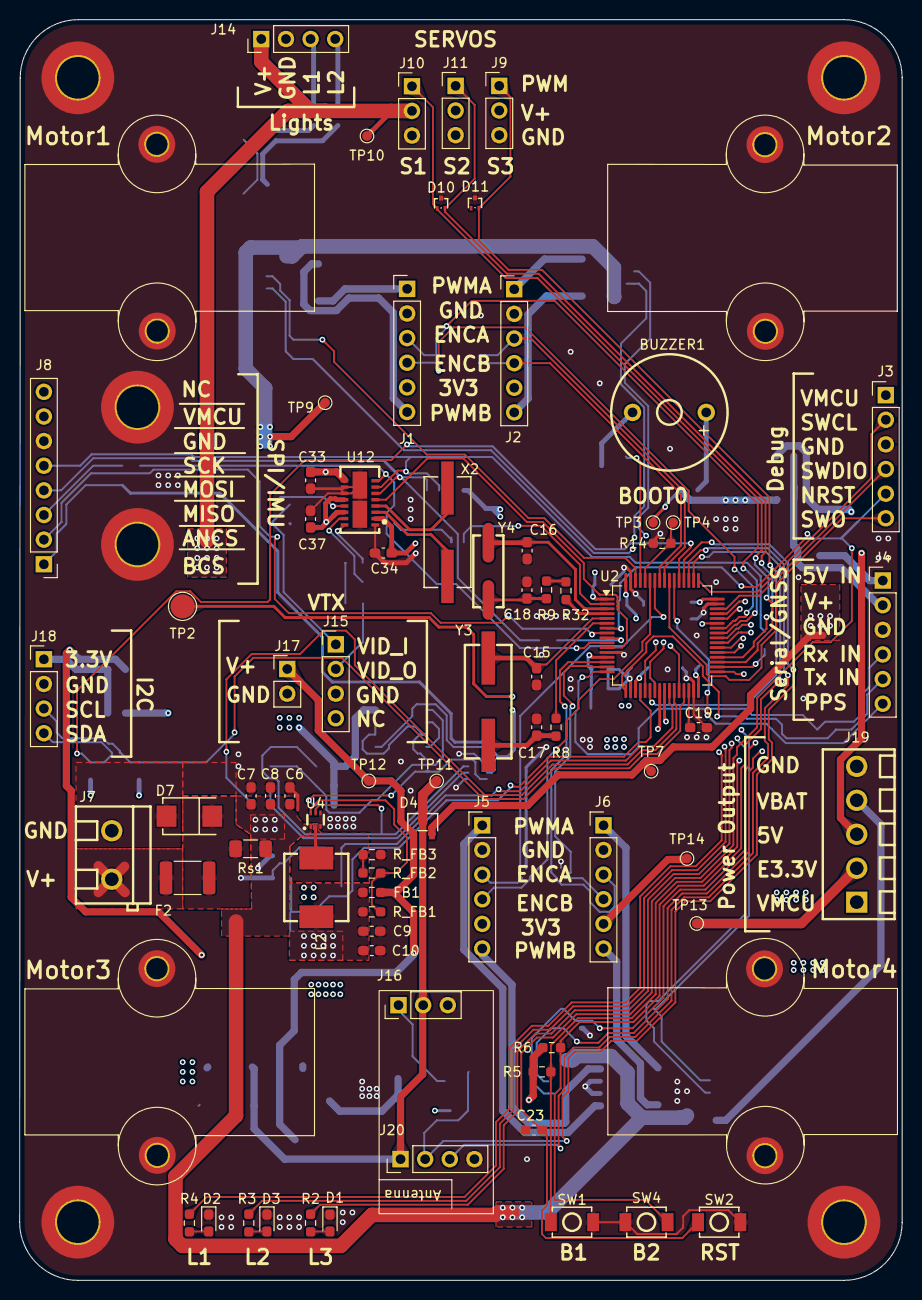
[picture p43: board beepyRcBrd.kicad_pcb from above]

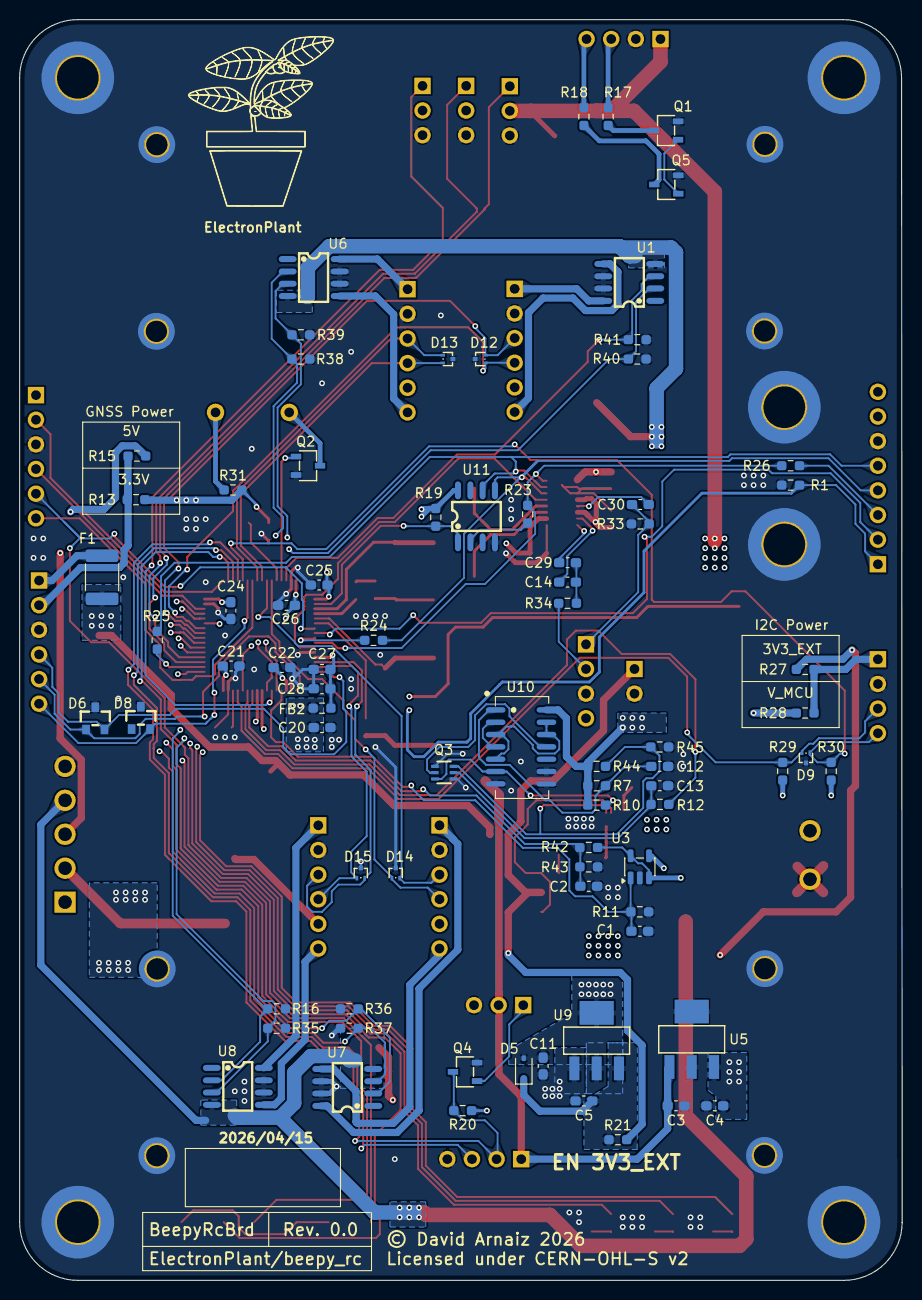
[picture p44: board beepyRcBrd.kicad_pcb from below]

Board: 4 copper layers, 91.0 x 130.0 mm, 171 parts (78 on the bottom side), 112 nets.

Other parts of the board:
Motor1, Motor2, Motor3, Motor4: Motor

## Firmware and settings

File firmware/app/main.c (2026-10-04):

/**
 * @file      main.c
 * @brief     Main.
 *
 * @ingroup   Main
 * @version   V0.0
 * @author    David Arnaiz
 * @copyright 2025 David Arnaiz
 *
 * This file is part of BeepyRC (https://github.com/ElectronPlant/beepy_rc).
 * This project is licensed under the GNU General Public License v3.0 license.
 *
 * @note Module Prefix: Main_
 *
 */

#include "FreeRTOS.h"
#include "string.h"
#include "task.h"

#include "plt_assert.h"

#include "bsp.h"
#include "controller.h"
#include "rc.h"
#include "supervisor.h"


/** @addtogroup App
 *   @{
 */

/** @addtogroup Main
 *   @{
 */

/********************************************************************************
 * Function Implementations
 ********************************************************************************/

/**
 * @brief Initializes the hardware components.
 */
static void Main_InitBoard(void) {
    bool_t ok;

    ok = BSP_Init();
    PLT_ASSERT(DEF_TRUE == ok);
}

/**
 * @brief  Initializes the application modules.
 */
static void Main_InitModules(void) {
    bool_t ok;

    /* Rx module */
    ok = Rc_Init();
    PLT_ASSERT(DEF_TRUE == ok);

    /* Motion module */
    ok = Ctrlr_Init();
    PLT_ASSERT(DEF_TRUE == ok);

    /* Supervisor module */
    ok = Super_Init();
    PLT_ASSERT(DEF_TRUE == ok);
}

/**
 * @brief  The application entry point.
 * @retval int
 */
int main(void) {
    /* Start up */
    Main_InitBoard();
    Main_InitModules();

    /* Run scheduler */
    vTaskStartScheduler();
    PLT_UNREACHABLE;
}


/******************************************
 * FreeRTOS
 ******************************************/
// TODO: check if needed.
void vApplicationTickHook(void) {}

void vApplicationMallocFailedHook(void) {
    taskDISABLE_INTERRUPTS();
    PLT_UNREACHABLE;
}

// TODO check if needed.
void vApplicationIdleHook(void) {}

/**
 * @brief  Stack overflow hook // TODO: implement
 */
void vApplicationStackOverflowHook(TaskHandle_t xTask, char* pcTaskName) {
    /* Check pcTaskName for the name of the offending task,
     * or pxCurrentTCB if pcTaskName has itself been corrupted. */
    (void)xTask;
    (void)pcTaskName;
    PLT_UNREACHABLE;
}

/** @} (end addtogroup Main)   */
/** @} (end addtogroup App)    */

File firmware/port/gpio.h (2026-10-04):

/**
 * @file  gpio.h
 * @brief Driver for the GPIOs.
 *
 * @ingroup   Gpio
 * @version   V0.0
 * @author    David Arnaiz
 * @copyright 2026 David Arnaiz
 *
 * This file is part of BeepyRC (https://github.com/ElectronPlant/beepy_rc).
 * This project is licensed under the GNU General Public License v3.0 license.
 */

#ifndef __GPIO_H__
#define __GPIO_H__

#include "plt_types.h"


/** @addtogroup Port
 *    @{
 */

/** @addtogroup Gpio
 *    @{
 */


/********************************************************************************
 * Defines
 ********************************************************************************/
#define GPIO_BOOL_TO_VALUE(X) (X == DEF_TRUE ? GPIO_VALUE_HIGH : GPIO_VALUE_LOW)
#define GPIO_VALUE_TO_BOOL(X) (X == GPIO_VALUE_HIGH ? DEF_TRUE : DEF_FALSE)

/********************************************************************************
 * Typedefs
 ********************************************************************************/
typedef enum GPIO_MODE_E {
    GPIO_MODE_INPUT = 0,
    GPIO_MODE_OUTPUT,
} GPIO_MODE_T;

typedef enum GPIO_VALUE_E {
    GPIO_VALUE_LOW = 0,
    GPIO_VALUE_HIGH,
} GPIO_VALUE_T;

typedef enum GPIO_PULL_E {
    GPIO_PULL_NONE = 0,
    GPIO_PULL_DOWN,
    GPIO_PULL_UP,
} GPIO_PULL_T;

typedef enum GPIO_STATUS_E {
    GPIO_STATUS_UNINITIALIZED = 0,
    GPIO_STATUS_INITIALIZED,
    GPIO_STATUS_RUNNING,
} GPIO_STATUS_T;

typedef const GPIO_PERIPHERAL_PORT_T* GPIO_PERIPHERAL_T;

typedef struct GPIO_INSTANCE_S {
    GPIO_STATUS_T           Status; /* Must be set to GPIO_STATUS_UNINITIALIZED on the struct def */
    GPIO_MODE_T             Mode;
    GPIO_PULL_T             Pull;
    const GPIO_PERIPHERAL_T Peripheral_Ptr;
} GPIO_INSTANCE_T;

typedef GPIO_INSTANCE_T* GPIO_HANDLER_T;


/********************************************************************************
 * Local Vars
 ********************************************************************************/

/********************************************************************************
 * Function Prototypes
 ********************************************************************************/
/**
 * @brief  Initializes the GPIO. See note 1.
 *
 * @param  gpio Gpio handler.
 *
 * @return DEF_TRUE if successful, DEF_FALSE otherwise.
 *
 * @note List of notes:
 *       1. The gpio instance must be uninitialized before being uninitialized.
 */
bool_t Gpio_Init(GPIO_HANDLER_T gpio);

/**
 * @brief  Sets the output of the specified GPIO.
 *
 * @param  gpio GPIO handler.
 * @param  value Value to set.
 */
void Gpio_Write(GPIO_HANDLER_T gpio, GPIO_VALUE_T value);

/**
 * @brief  Toggles the output of the specified GPIO.
 *
 * @param  gpio GPIO handler.
 */
void Gpio_Toggle(GPIO_HANDLER_T gpio);

/**
 * @brief  Reads the output of the specified GPIO.
 *
 * @param  gpio GPIO handler.
 *
 * @return Read value.
 */
GPIO_VALUE_T Gpio_Read(GPIO_HANDLER_T gpio);


/** @} (end addtogroup Port)        */
/** @} (end addtogroup Gpio)        */

#endif /* __GPIO_H__       */

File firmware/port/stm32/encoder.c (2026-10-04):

/**
 * @file  encoder.h
 * @brief STM32 port of the motor encoder driver.
 *
 * @ingroup   EncoderStm32
 * @version   V0.0
 * @author    David Arnaiz
 * @copyright 2025 David Arnaiz
 *
 * This file is part of BeepyRC (https://github.com/ElectronPlant/beepy_rc).
 * This project is licensed under the GNU General Public License v3.0 license.
 *
 * @note    Module Prefix: Enc_
 */

#include "plt_assert.h"
#include "plt_types.h"

#include "encoder_port.h"
#include "target.h"

#include "encoder.h"


/** @addtogroup Port
 *   @{
 */

/** @addtogroup Encoder
 *   @{
 */

/** @addtogroup EncoderStm32
 *   @{
 */

/********************************************************************************
 * Defines
 ********************************************************************************/
/**
 * Running encoder asserts are set in all the functions that are not init, start
 * or stop. This macro control if the state of the encoder is checked when the
 * other functions are called (when set to 1) or not (when set to 0).
 */
#define ENC_ENABLE_RUNNING_ASSERT 1

#if ENC_ENABLE_RUNNING_ASSERT == 1
    #define ENC_RUNNING_ASSERT(enc) PLT_ASSERT(ENC_STATUS_RUNNING == enc->Status)
#else
    #define ENC_RUNNING_ASSERT(enc)
#endif /* ENC_ENABLE_RUNNING_ASSERT == 1 */

/********************************************************************************
 * Typedefs
 ********************************************************************************/

/********************************************************************************
 * Function Prototypes
 ********************************************************************************/

/********************************************************************************
 * Local Vars
 ********************************************************************************/

/********************************************************************************
 * Function Implementations
 ********************************************************************************/

/**
 * @brief  STM32 port for the encoder init function.
 */
bool_t Enc_Init(ENC_HANDLER_T enc) {
    ErrorStatus err;

    PLT_ASSERT(NULL != enc);
    PLT_ASSERT(ENC_STATUS_UNINITIALIZED == enc->Status);

    /* Initialize the encoder timer */
    enc->Peripheral->TimerClkEnFn_Ptr(enc->Peripheral->TimerClk);
    LL_TIM_ENCODER_InitTypeDef enc_cfg = {
        .EncoderMode = LL_TIM_ENCODERMODE_X4_TI12,     /* Count on both edges */
        .IC1Polarity = LL_TIM_IC_POLARITY_RISING,      /* Polarity for input 1 */
        .IC1ActiveInput = LL_TIM_ACTIVEINPUT_DIRECTTI, /* ICx is mapped on TIx */
        .IC1Prescaler = LL_TIM_ICPSC_DIV1,
        .IC1Filter = LL_TIM_IC_FILTER_FDIV1,
        .IC2Polarity = LL_TIM_IC_POLARITY_RISING,      /* Polarity for input 1 */
        .IC2ActiveInput = LL_TIM_ACTIVEINPUT_DIRECTTI, /* ICx is mapped on TIx */
        .IC2Prescaler = LL_TIM_ICPSC_DIV1,
        .IC2Filter = LL_TIM_IC_FILTER_FDIV1,
    };
    LL_TIM_ENCODER_Init(enc->Peripheral->Timer, &enc_cfg);

    LL_TIM_InitTypeDef tim_cfg = {
        .Prescaler = 0,
        .CounterMode = LL_TIM_COUNTERMODE_UP,
        .Autoreload = 65535, /* Set to the max allowed by the timer */
        .ClockDivision = LL_TIM_CLOCKDIVISION_DIV1,
        .RepetitionCounter = 0,
    };
    err = LL_TIM_Init(enc->Peripheral->Timer, &tim_cfg);
    if (SUCCESS != err) {
        return DEF_FALSE;
    }

    LL_TIM_DisableARRPreload(enc->Peripheral->Timer);
    LL_TIM_SetTriggerOutput(enc->Peripheral->Timer, LL_TIM_TRGO_RESET);
    LL_TIM_DisableMasterSlaveMode(enc->Peripheral->Timer);

    /* Initialize GPIO 1 */
    enc->Peripheral->Gpio1ClkEnFn_Ptr(enc->Peripheral->Gpio1Clk);
    LL_GPIO_InitTypeDef gpio1_cfg = {
        .Pin = enc->Peripheral->Gpio1Pin,
        .Mode = LL_GPIO_MODE_ALTERNATE,
        .Speed = LL_GPIO_SPEED_FREQ_LOW,
        .OutputType = LL_GPIO_OUTPUT_PUSHPULL,
        .Pull = LL_GPIO_PULL_NO,
        .Alternate = enc->Peripheral->Gpio1AlternateFunc,
    };
    err = LL_GPIO_Init(enc->Peripheral->Gpio1Port, &gpio1_cfg);
    if (SUCCESS != err) {
        return DEF_FALSE;
    }

    /* Initialize GPIO 2 */
    enc->Peripheral->Gpio2ClkEnFn_Ptr(enc->Peripheral->Gpio2Clk);
    LL_GPIO_InitTypeDef gpio2_cfg = {
        .Pin = enc->Peripheral->Gpio2Pin,
        .Mode = LL_GPIO_MODE_ALTERNATE,
        .Speed = LL_GPIO_SPEED_FREQ_LOW,
        .OutputType = LL_GPIO_OUTPUT_PUSHPULL,
        .Pull = LL_GPIO_PULL_NO,
        .Alternate = enc->Peripheral->Gpio2AlternateFunc,
    };
    err = LL_GPIO_Init(enc->Peripheral->Gpio2Port, &gpio2_cfg);
    if (SUCCESS != err) {
        return DEF_FALSE;
    }

    enc->Status = ENC_STATUS_INITIALIZED;
    return DEF_TRUE;
}

/**
 * @brief  STM32 port of the encoder start function.
 */
void Enc_StartEncoder(ENC_HANDLER_T enc) {
    PLT_ASSERT(NULL != enc);
    PLT_ASSERT(ENC_STATUS_INITIALIZED == enc->Status);

    LL_TIM_CC_DisableChannel(
        enc->Peripheral->Timer,
        enc->Peripheral->TimerChn1 | enc->Peripheral->TimerChn2
    );
    LL_TIM_CC_EnableChannel(
        enc->Peripheral->Timer,
        enc->Peripheral->TimerChn1 | enc->Peripheral->TimerChn2
    );
    enc->Peripheral->Timer->CR1 |= TIM_CR1_CEN;

    enc->Peripheral->Timer->CNT = 0;
    enc->Status = ENC_STATUS_RUNNING;
}

/**
 * @brief  STM32 port of the stop encoder function.
 */
void Enc_StopEncoder(ENC_HANDLER_T enc) {
    PLT_ASSERT(NULL != enc);
    PLT_ASSERT(ENC_STATUS_RUNNING == enc->Status);

    LL_TIM_CC_DisableChannel(
        enc->Peripheral->Timer,
        enc->Peripheral->TimerChn1 | enc->Peripheral->TimerChn2
    );
    enc->Peripheral->Timer->CR1 &= ~TIM_CR1_CEN;

    enc->Status = ENC_STATUS_INITIALIZED;
}

/**
 * @brief  STM32 port for the get encoder count function.
 */
uint32_t Enc_GetCount(ENC_HANDLER_T enc) {
    PLT_ASSERT(NULL != enc);
    ENC_RUNNING_ASSERT(enc);
    return LL_TIM_GetCounter(enc->Peripheral->Timer);
}

/**
 * @brief  STM32 port for the reset encoder count function.
 */
void Enc_ResetCount(ENC_HANDLER_T enc) {
    ENC_RUNNING_ASSERT(enc);
    enc->Peripheral->Timer->CNT = 0;
}

/**
 * @brief  STM32 port for the get encoder direction function.
 */
ENC_DIRECTION_T Enc_GetDirection(ENC_HANDLER_T enc) {
    ENC_RUNNING_ASSERT(enc);
    return LL_TIM_GetDirection(enc->Peripheral->Timer) == 1U ? ENC_DIRECTION_UP
                                                             : ENC_DIRECTION_DOWN;
}


/** @} (end addtogroup EncoderStm32) */
/** @} (end addtogroup Encoder)      */
/** @} (end addtogroup Port)         */

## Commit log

2025-07-01 feat: fist commit
    first commit includes:
    - Documentaion setup.
    - STM32 drivers.
    - Basic Makefile.
    - Minimal app with basic SBUS support.
    - Licensing information.
    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
2025-07-16 feat: removing hall dependencies for systick
2025-12-07 feat: Preliminary support for encoders
2025-12-08 feat: completed support for multiple encoders
2025-12-10 test: testing PWM + encoders
2025-12-17 refactor: generalize the PWM timer implementation
2025-12-17 chore: adding missing asserts on the encoder module
    [encoder.c]
2025-12-25 refactor: clean up pwm timer and encoder dirvers
2025-12-25 feat: motor driver
2025-12-31 feat: adding support for multiple motors
2026-02-28 feat: brd schematics v0.0
    [3v3_external_reg.kicad_sch, 3v_reg.kicad_sch, 5v_reg.kicad_sch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]
2026-03-01 fix: motor PWM pulled down
    [BOM_complete.ods, BOM_ordering.xlsx, drive.kicad_sch]
2026-03-01 feat: adding servo motor support
2026-03-01 fix: net names
    [beepyRcBrd.kicad_sch, io.kicad_sch, rc.kicad_sch]
2026-03-01 chore: updating HW documentation
    [BOM_complete.ods]
2026-03-01 fix: passing schematics ERC rules
    [bat_mon.kicad_sch, beepyRcBrd.kicad_pcb, beepyRcBrd.kicad_sch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]
2026-04-18 feat: completed beepyRcBrd_rev_0_0.pdf
    [3v3_external_reg.kicad_sch, 3v_reg.kicad_sch, BOM_complete.ods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]
2026-04-26 refactor: move board specific defines to the target file
2026-05-10 feat: RC improve error handling and added RC inputs
    [sbus.h]
2026-05-10 fix: remove compilation warning on print
2026-05-10 feat: adding travel based control for servos
2026-05-10 feat: RC input to PWM output
2026-08-05 feat: adding support for user buttons
2026-08-17 feat: adding power off aux peripheral
2026-08-31 feat: adding buzzer support
    [pwm_timer.c, pwm_timer.h]
2026-10-03 fix: false power button detection
    [ui.c]

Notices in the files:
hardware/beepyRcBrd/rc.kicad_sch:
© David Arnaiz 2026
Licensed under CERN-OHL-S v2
